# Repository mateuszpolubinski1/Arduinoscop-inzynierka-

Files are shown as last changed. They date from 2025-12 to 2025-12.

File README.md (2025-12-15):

# ArduinoScope – Modular Educational Measurement Device
*A universal, low-cost measurement platform based on Raspberry Pi Pico*

19797808-9ae3-465f-a71c-d99da3b4bd1f

---

## Overview
ArduinoScope is a **modular electronic measurement device** designed as an educational platform for electronics and metrology laboratories.  
The project was developed as an **engineering thesis** and combines **analog front-end design**, **ADC-based signal acquisition**, and **embedded software development**.

The device is built around the **Raspberry Pi Pico (RP2040)** microcontroller and can be reconfigured via software to operate as:
- Oscilloscope
- Spectrum analyzer
- Wobuloscope
- Vector voltmeter
- Frequency counter

---

## System Architecture
The system is based on a **modular architecture**, consisting of a mainboard and multiple plug-in expansion modules.



Key blocks of the system:
- Modular analog input boards
- Mainboard with Raspberry Pi Pico (RP2040)
- Internal ADC for signal acquisition
- TFT display with touchscreen
- USB interface for communication with a PC
- Dedicated power supply module

---

## Analog Front-End Design
Two independent analog input paths were designed to support different measurement scenarios.

### Differential Input Path


- Based on **INA2137 instrumentation amplifier**
- Fixed gain using precision, internally matched resistors
- High common-mode rejection (CMRR)
- Enables voltage measurement between any two points in a circuit
- Dedicated overvoltage protection to protect the ADC

---

### Single-Ended Input Path


- Based on **OPA1644 / TL084 operational amplifiers**
- Electronically adjustable gain
- Separate signal paths for DC and AC components
- Software-controlled signal conditioning similar to a classic oscilloscope
- Input and output protection for safe educational use

---

## Protection & Signal Conditioning
To ensure robustness and safe operation:
- Input protection using **BAV99-AQ diodes** (low leakage, low capacitance)
- ADC protection using **BAS40 Schottky diodes**
- Precision voltage references (**TL431**, **LM385**) for proper ADC range adaptation
- Designed to withstand accidental overvoltage conditions during laboratory exercises

---

## PCB Design
Custom printed circuit boards were designed using **KiCad**, with particular attention to analog signal integrity.











PCB design highlights:
- Modular plug-in boards connected via pin headers
- Noise-aware routing and ground plane usage
- Separation of analog and digital sections
- Easy manufacturing and repair

---

## Software
The firmware was developed using:
- **Arduino**
- **MicroPython**

Main software features:
- Data acquisition from internal ADC
- Signal processing and scaling
- User interface handling (display and touchscreen)
- USB communication for offline data transfer to PC

---

## Measurements & Validation
The device was validated through laboratory measurements.




Validation results:
- Correct operation within the acoustic frequency range
- Stable gain and offset control
- Proper operation of protection circuits
- Reliable signal acquisition using the RP2040 ADC

---

## User Interface
The built-in TFT display provides direct visualization of measured signals.

The user interface allows real-time interaction and configuration without the need for an external computer.

---

## Technologies Used
**Hardware**
- Raspberry Pi Pico (RP2040)
- INA2137, OPA1644, TL084
- AD9850 signal generator
- PCF8575 I/O expander

**Software & Tools**
- Arduino, MicroPython
- KiCad, LTspice
- Oscilloscope and laboratory measurement equipment

---

## Project Status & Future Work
Status:
- Fully functional prototype
- Successfully tested in laboratory conditions

Possible future improvements:
- External higher-resolution ADC
- Improved bandwidth and noise performance
- PC-based visualization and analysis software

---

## Author
**Mateusz Połubiński**  
Electronics Engineering – Warsaw University of Technology

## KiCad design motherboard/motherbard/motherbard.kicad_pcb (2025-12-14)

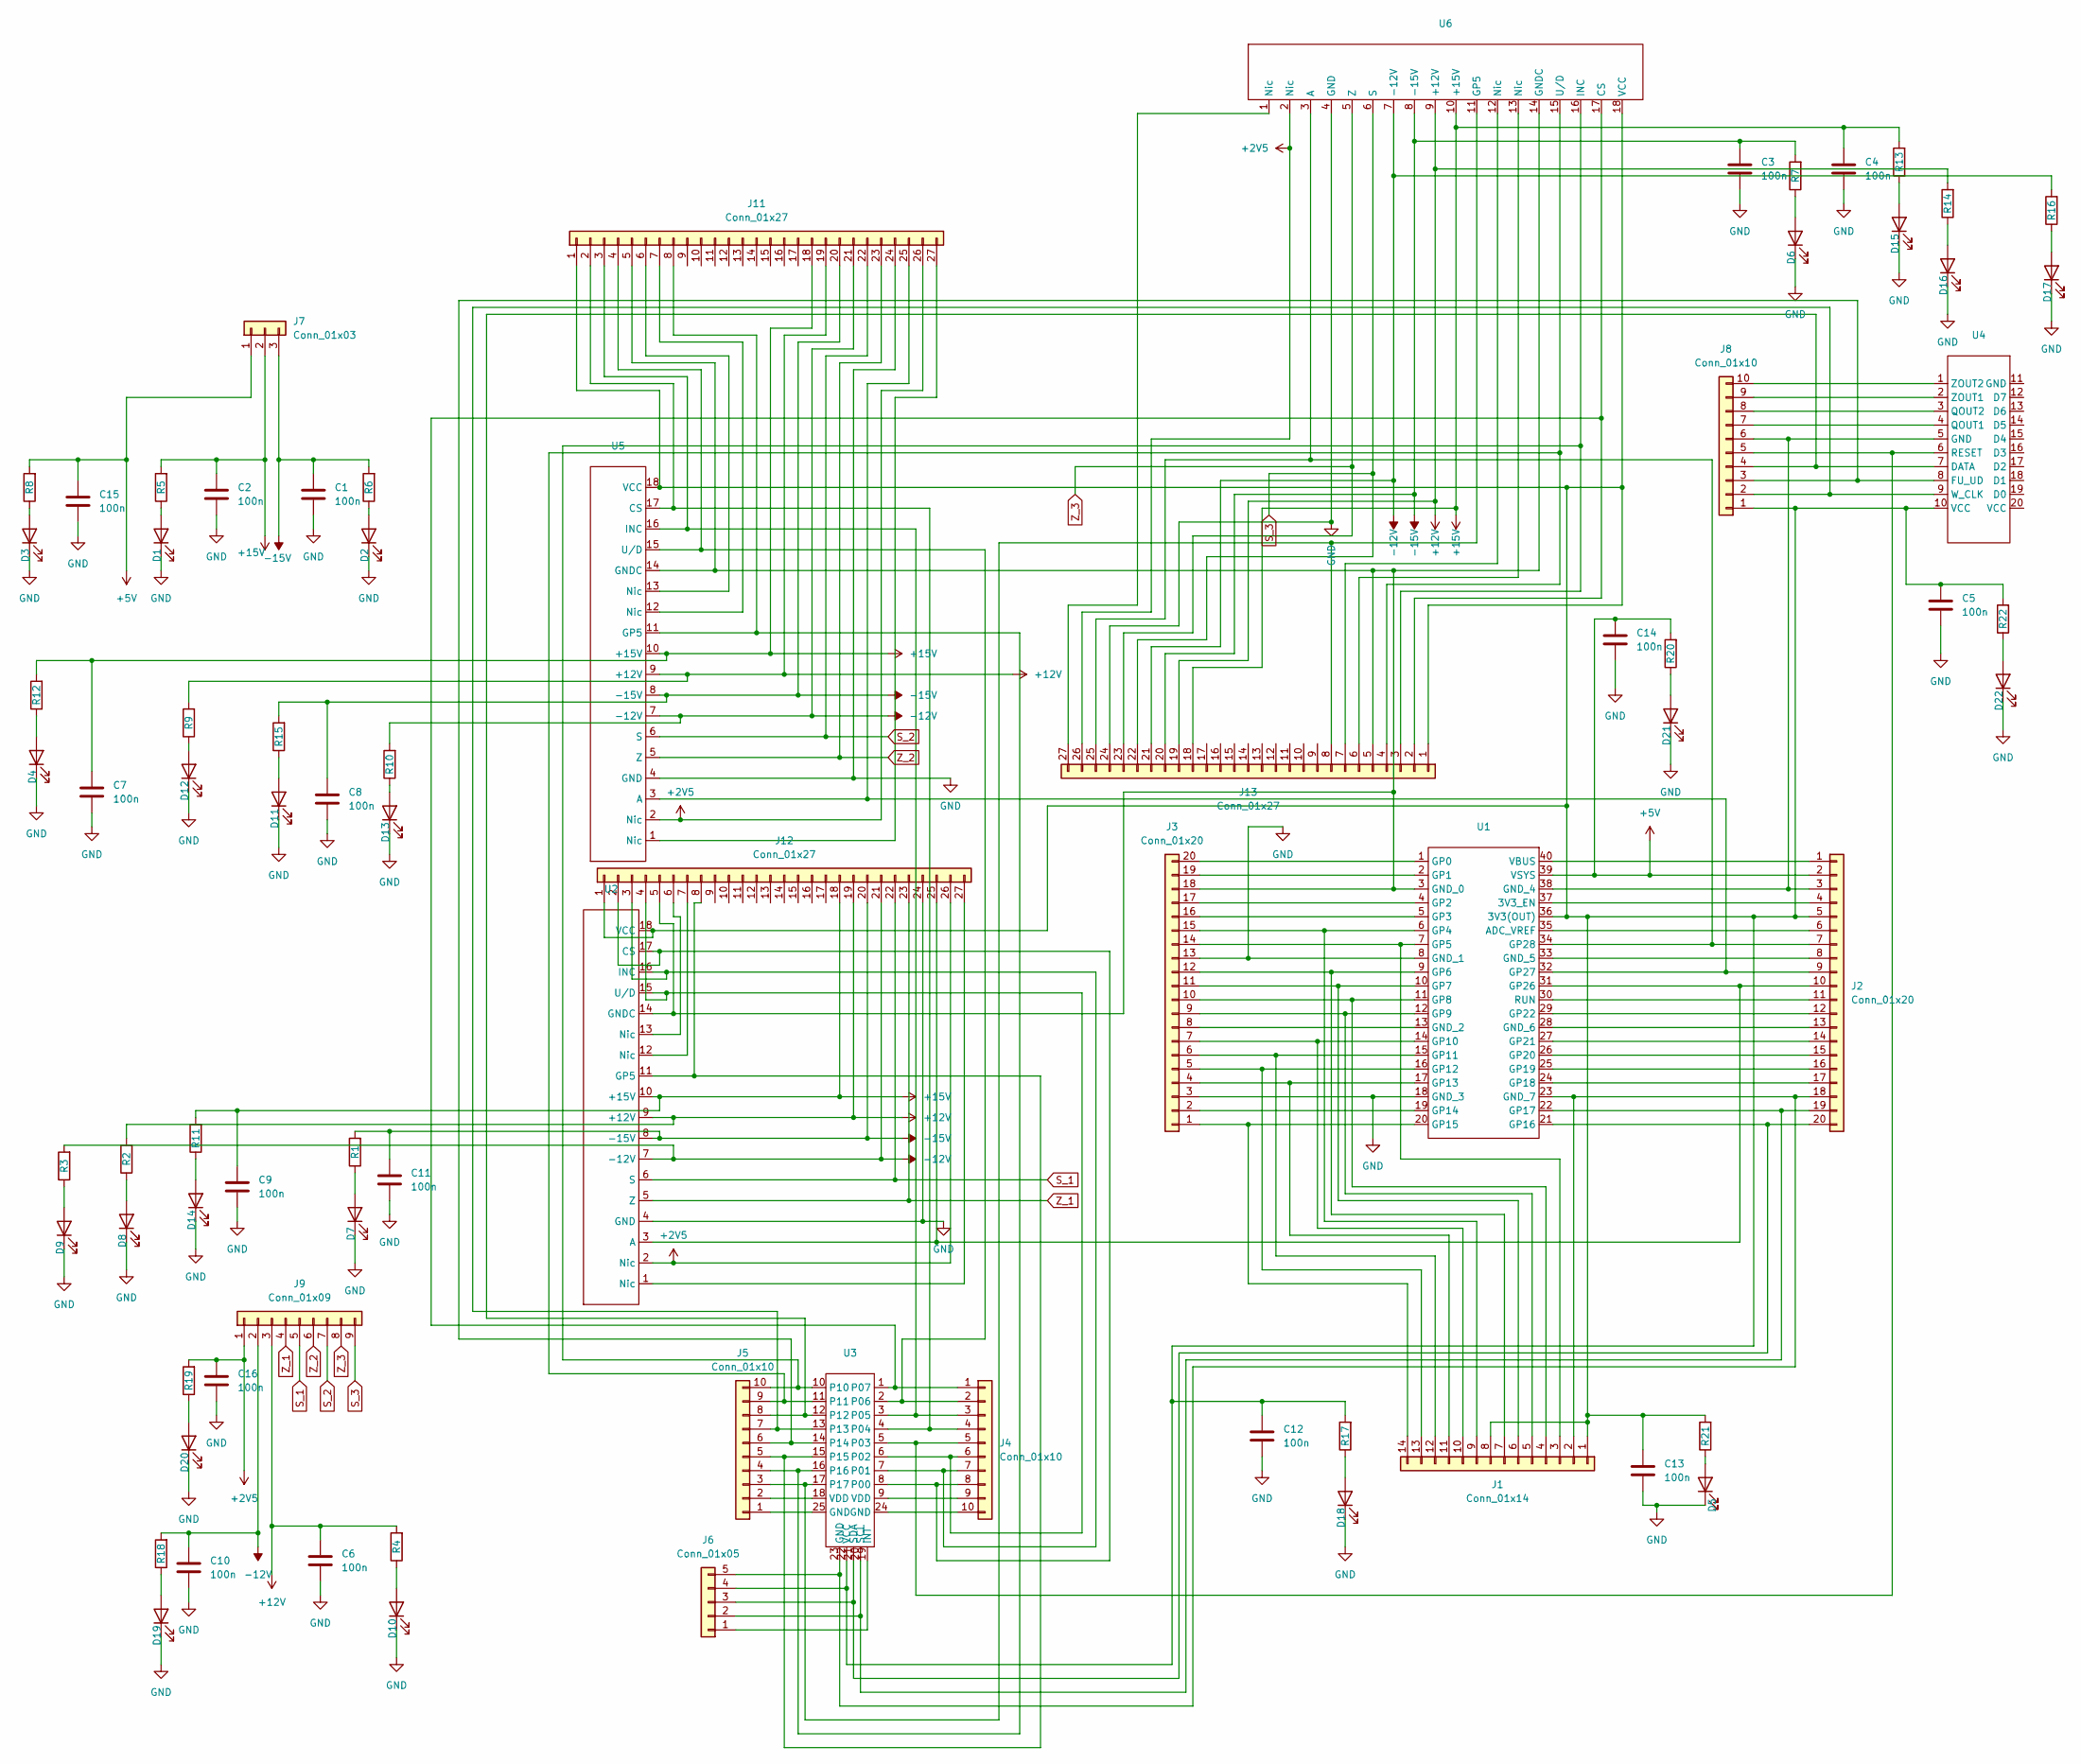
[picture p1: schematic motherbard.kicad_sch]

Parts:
C1, C2, C3, C4, C5, C6, C7, C8, C9, C10, C11, C12, C13, C14, C15, C16: 100n; C_1206_3216Metric_Pad1.33x1.80mm_HandSolder
D1, D2, D3, D4, D5, D6, D7, D8, D9, D10, D11, D12, D13, D14, D15, D16, D17, D18, D19, D20, D21, D22: IR26-21C_L110_TR8; LED_1206_3216Metric
J1: Conn_01x14; PinSocket_1x14_P2.54mm_Vertical
J2, J3: Conn_01x20; PinSocket_1x20_P2.54mm_Vertical
J4, J5, J8: Conn_01x10; PinHeader_1x10_P2.54mm_Vertical
J6: Conn_01x05; PinHeader_1x05_P2.54mm_Vertical
J7: Conn_01x03; PinHeader_1x03_P2.54mm_Vertical
J9: Conn_01x09; PinHeader_1x09_P2.54mm_Vertical
J11, J12, J13: Conn_01x27; PinSocket_1x27_P2.54mm_Vertical
R1, R2, R3, R4, R5, R6, R7, R8, R9, R10, R11, R12, R13, R14, R15, R16, R17, R18, R19, R20, R21, R22: R; R_1206_3216Metric_Pad1.30x1.75mm_HandSolder
U1: raspberry pi pico
U2, U5, U6: płytka
U3: ekspander
U4: generator

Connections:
+2V5: C16.1, J9.1, J11.26, J12.26, J13.26, R19.2, U2.2 (Nic), U5.2 (Nic), U6.2 (Nic)
+5V: C14.1, C15.1, J2.2, J7.1, R8.2, R20.2, U1.39 (VSYS)
+12V: C6.1, J9.3, J11.19, J12.19, J13.19, R2.2, R4.2, R9.2, R14.2, U2.9 (+12V), U5.9 (+12V), U6.9 (+12V)
+15V: C2.1, C4.1, C7.1, C9.1, J7.2, J11.18, J12.18, J13.18, R5.2, R11.2, R12.2, R13.2, U2.10 (+15V), U5.10 (+15V), U6.10 (+15V)
-12V: C10.1, J9.2, J11.21, J12.21, J13.21, R3.2, R10.2, R16.2, R18.2, U2.7 (-12V), U5.7 (-12V), U6.7 (-12V)
-15V: C1.1, C3.1, C8.1, C11.1, J7.3, J11.20, J12.20, J13.20, R1.2, R6.2, R7.2, R15.2, U2.8 (-15V), U5.8 (-15V), U6.8 (-15V)
GND: C1.2, C2.2, C3.2, C4.2, C5.2, C6.2, C7.2, C8.2, C9.2, C10.2, C11.2, C12.2, C13.2, C14.2, C15.2, C16.2, D1.1 (K), D2.1 (K), D3.1 (K), D4.1 (K), D5.1 (K), D6.1 (K), D7.1 (K), D8.1 (K), D9.1 (K), D10.1 (K), D11.1 (K), D12.1 (K), D13.1 (K), D14.1 (K), D15.1 (K), D16.1 (K), D17.1 (K), D18.1 (K), D19.1 (K), D20.1 (K), D21.1 (K), D22.1 (K), J3.3, J3.13, J11.24, J12.24, J13.24, U1.8 (GND_1), U1.18 (GND_3), U2.4 (GND), U5.4 (GND), U6.4 (GND)
unnamed: D1.2 (A), R5.1
unnamed: D2.2 (A), R6.1
unnamed: D3.2 (A), R8.1
unnamed: D4.2 (A), R12.1
unnamed: D5.2 (A), R21.1
unnamed: D6.2 (A), R7.1
unnamed: D7.2 (A), R1.1
unnamed: D8.2 (A), R2.1
unnamed: D9.2 (A), R3.1
unnamed: D10.2 (A), R4.1
unnamed: D11.2 (A), R15.1
unnamed: D12.2 (A), R9.1
unnamed: D13.2 (A), R10.1
unnamed: D14.2 (A), R11.1
unnamed: D15.2 (A), R13.1
unnamed: D16.2 (A), R14.1
unnamed: D17.2 (A), R16.1
unnamed: D18.2 (A), R17.1
unnamed: D19.2 (A), R18.1
unnamed: D20.2 (A), R19.1
unnamed: D21.2 (A), R20.1
unnamed: D22.2 (A), R22.1
unnamed: C5.1, C12.1, C13.1, J1.1, J1.8, J2.5, J6.4, J8.1, J11.1, J12.1, J13.1, R17.2, R21.2, R22.2, U1.36 (3V3(OUT)), U2.18 (VCC), U3.22 (VCC), U4.10 (VCC), U5.18 (VCC), U6.18 (VCC)
unnamed: J1.2, J2.18, J6.5, U1.23 (GND_7), U3.23 (GND)
unnamed: J1.3, J3.14, U1.7 (GP5)
unnamed: J1.4, J3.10, U1.11 (GP8)
unnamed: J1.5, J3.9, U1.12 (GP9)
unnamed: J1.6, J3.11, U1.10 (GP7)
unnamed: J1.7, J3.12, U1.9 (GP6)
unnamed: J1.9, J3.15, U1.6 (GP4)
unnamed: J1.10, J3.7, U1.14 (GP10)
unnamed: J1.11, J3.4, U1.17 (GP13)
unnamed: J1.12, J3.6, U1.15 (GP11)
unnamed: J1.13, J3.5, U1.16 (GP12)
unnamed: J1.14, J3.1, U1.20 (GP15)
unnamed: J2.1, U1.40 (VBUS)
unnamed: J2.3, J8.6, U1.38 (GND_4), U4.5 (GND)
unnamed: J2.4, U1.37 (3V3_EN)
unnamed: J2.6, U1.35 (ADC_VREF)
unnamed: J2.8, U1.33 (GND_5)
unnamed: J2.11, U1.30 (RUN)
unnamed: J2.12, U1.29 (GP22)
unnamed: J2.13, U1.28 (GND_6)
unnamed: J2.14, U1.27 (GP21)
unnamed: J2.15, U1.26 (GP20)
unnamed: J2.16, U1.25 (GP19)
unnamed: J2.17, U1.24 (GP18)
unnamed: J2.19, J6.2, U1.22 (GP17), U3.20 (SCL)
unnamed: J2.20, J6.3, U1.21 (GP16), U3.21 (SDA)
unnamed: J3.2, U1.19 (GP14)
unnamed: J3.8, U1.13 (GND_2)
unnamed: J3.16, U1.5 (GP3)
unnamed: J3.17, U1.4 (GP2)
unnamed: J3.19, U1.2 (GP1)
unnamed: J3.20, U1.1 (GP0)
unnamed: J4.5, J8.5, U3.5 (P03), U4.6 (RESET)
unnamed: J4.9, U3.9 (VDD)
unnamed: J4.10, U3.24 (GND)
unnamed: J5.1, U3.25 (GND)
unnamed: J5.2, U3.18 (VDD)
unnamed: J5.6, J8.3, U3.14, U4.8 (FU_UD)
unnamed: J5.7, J8.2, U3.13, U4.9 (W_CLK)
unnamed: J5.8, J8.4, U3.12, U4.7 (DATA)
unnamed: J6.1, U3.19 (INT)
unnamed: J8.7, U4.4 (QOUT1)
unnamed: J8.8, U4.3 (QOUT2)
unnamed: J8.9, U4.2 (ZOUT1)
unnamed: J8.10, U4.1 (ZOUT2)
unnamed: J4.4, J11.2, U3.4, U5.17 (CS)
unnamed: J4.3, J11.3, U3.3 (P05), U5.16 (INC)
unnamed: J4.2, J11.4, U3.2 (P06), U5.15 (U/D)
unnamed: J3.18, J11.5, J12.5, J13.5, U1.3 (GND_0), U2.14 (GNDC), U5.14 (GNDC), U6.14 (GNDC)
unnamed: J11.6, U5.13 (Nic)
unnamed: J11.7, U5.12 (Nic)
unnamed: J5.4, J11.8, U3.16, U5.11 (GP5)
unnamed: J2.9, J11.25, U1.32 (GP27), U5.3 (A)
unnamed: J11.27, U5.1 (Nic)
unnamed: J4.8, J12.2, U2.17 (CS), U3.8 (P00)
unnamed: J4.7, J12.3, U2.16 (INC), U3.7 (P01)
unnamed: J4.6, J12.4, U2.15 (U/D), U3.6 (P02)
unnamed: J12.6, U2.13 (Nic)
unnamed: J12.7, U2.12 (Nic)
unnamed: J5.5, J12.8, U2.11 (GP5), U3.15
unnamed: J2.10, J12.25, U1.31 (GP26), U2.3 (A)
unnamed: J12.27, U2.1 (Nic)
unnamed: J4.1, J13.2, U3.1 (P07), U6.17 (CS)
unnamed: J5.10, J13.3, U3.10, U6.16 (INC)
unnamed: J5.9, J13.4, U3.11, U6.15 (U/D)
unnamed: J13.6, U6.13 (Nic)
unnamed: J13.7, U6.12 (Nic)
unnamed: J5.3, J13.8, U3.17, U6.11 (GP5)
unnamed: J2.7, J13.25, U1.34 (GP28), U6.3 (A)
unnamed: J13.27, U6.1 (Nic)
S_1: J9.5, J12.22, U2.6 (S)
S_2: J9.7, J11.22, U5.6 (S)
S_3: J9.9, J13.22, U6.6 (S)
Z_1: J9.4, J12.23, U2.5 (Z)
Z_2: J9.6, J11.23, U5.5 (Z)
Z_3: J9.8, J13.23, U6.5 (Z)

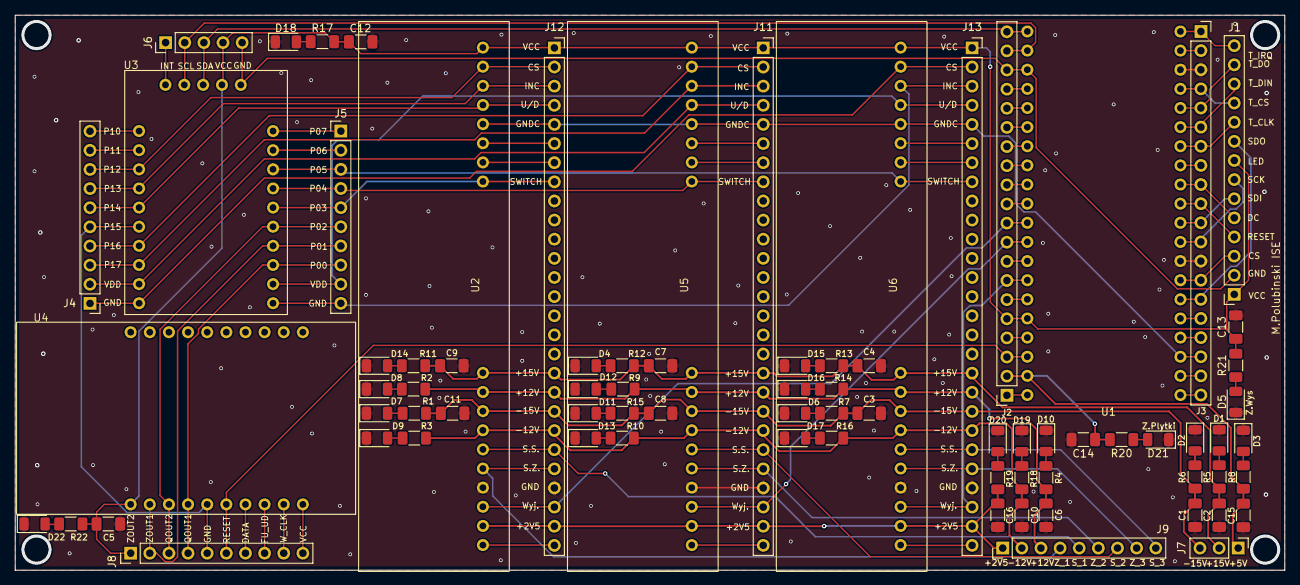
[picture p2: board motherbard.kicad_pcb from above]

Board: 2 copper layers, 168.5 x 73.7 mm, 78 parts (0 on the bottom side), 106 nets.

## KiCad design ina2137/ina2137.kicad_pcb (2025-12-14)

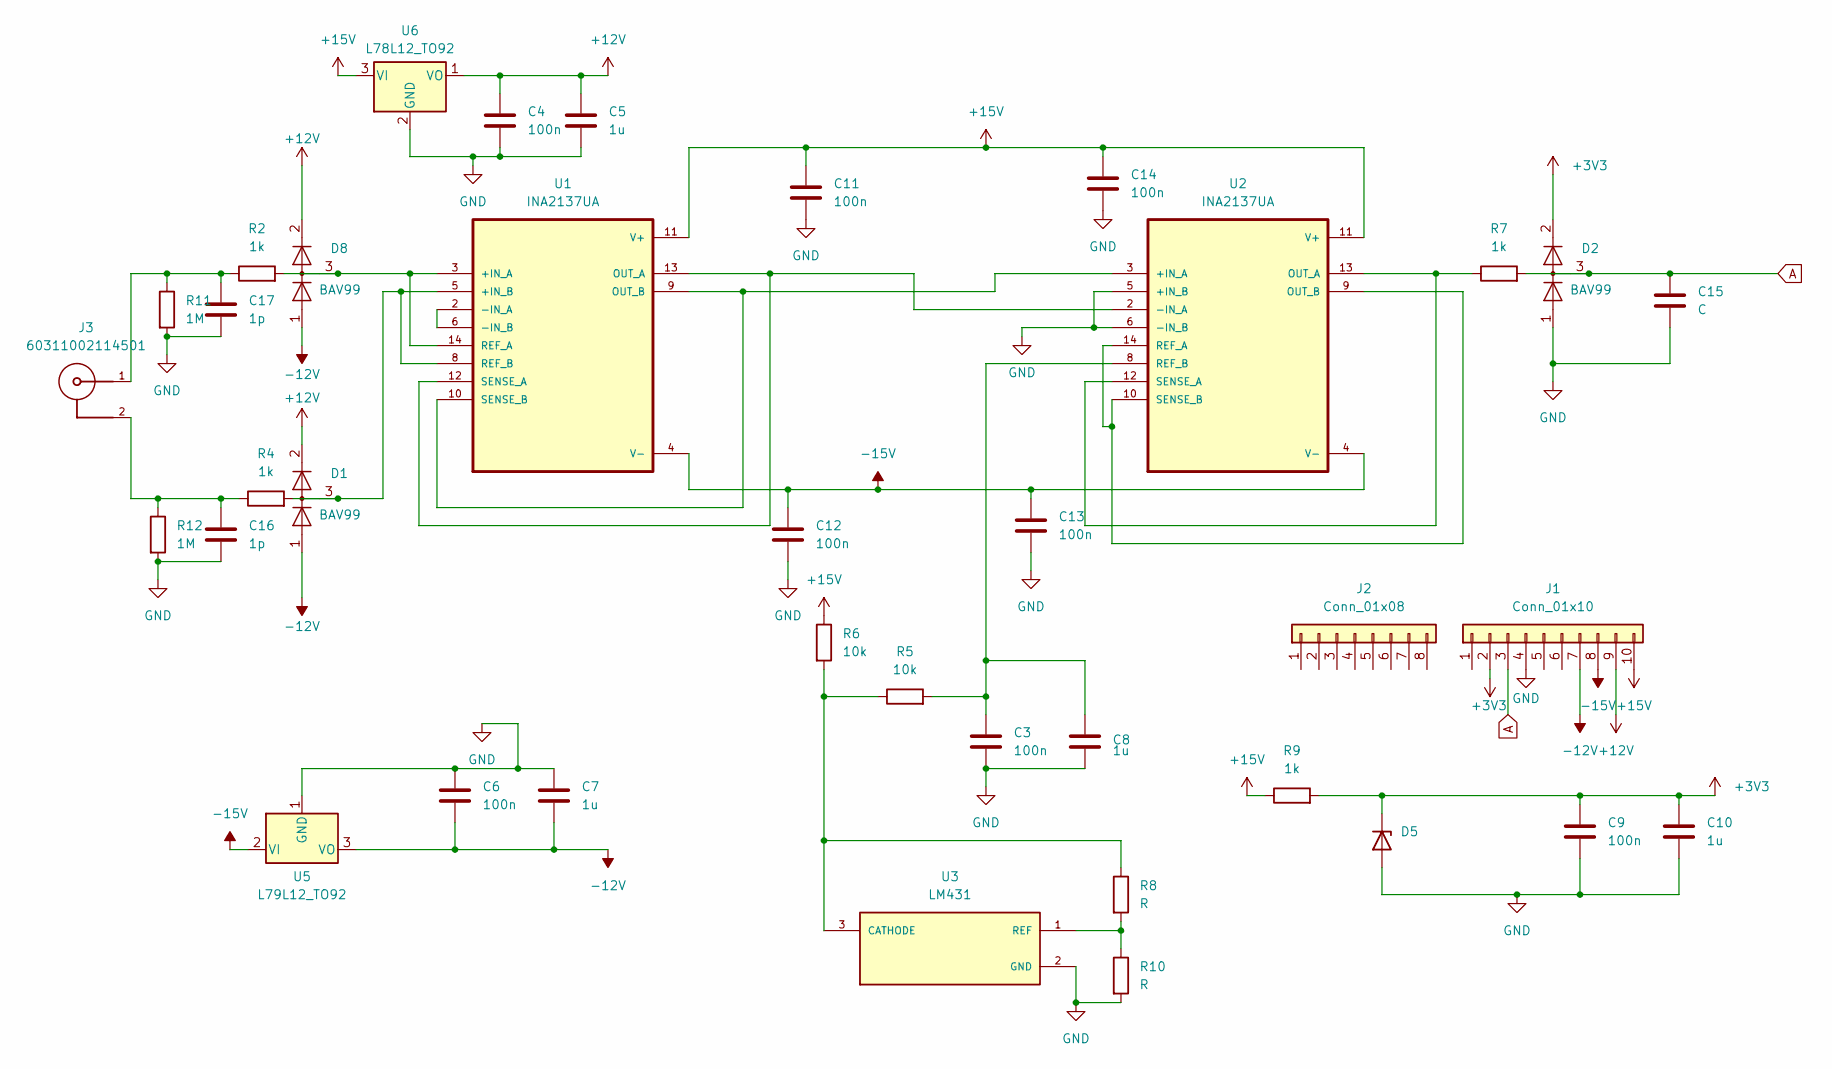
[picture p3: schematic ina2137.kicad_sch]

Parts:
C3, C4, C6, C9, C11, C12, C13, C14: 100n; C_1206_3216Metric_Pad1.33x1.80mm_HandSolder
C5, C7, C8, C10: 1u; CP_Radial_Tantal_D7.0mm_P5.00mm
C15: C; C_1206_3216Metric_Pad1.33x1.80mm_HandSolder
C16, C17: 1p; C_1206_3216Metric_Pad1.33x1.80mm_HandSolder
D1, D2, D8: BAV99; SOT-23
D5: D_A-405_P2.54mm_Vertical_KathodeUp
J1: Conn_01x10; PinHeader_1x10_P2.54mm_Vertical
J2: Conn_01x08; PinHeader_1x08_P2.54mm_Vertical
J3: 60311002114501; SMA_Molex_73251-2200_Horizontal; PART-NUMBER 60311002114501
R2, R4, R7, R9: 1k; R_1206_3216Metric_Pad1.30x1.75mm_HandSolder
R5, R6: 10k; R_1206_3216Metric_Pad1.30x1.75mm_HandSolder
R8, R10: R; R_1206_3216Metric_Pad1.30x1.75mm_HandSolder
R11, R12: 1M; R_1206_3216Metric_Pad1.30x1.75mm_HandSolder
U1, U2: INA2137UA; SOIC127P600X175-14N
U3: LM431; TO-92
U5: L79L12_TO92; TO-92_Inline
U6: L78L12_TO92; TO-92_Inline

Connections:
+3V3: C9.1, C10.1, D2.2 (A), D5.1 (K), J1.2, R9.2
+12V: C4.1, C5.1, D1.2 (A), D8.2 (A), J1.9, U6.1 (VO)
+15V: C11.1, C14.1, J1.10, R6.1, R9.1, U1.11 (V+), U2.11 (V+), U6.3 (VI)
-12V: C6.2, C7.2, D1.1 (K), D8.1 (K), J1.7, U5.3 (VO)
-15V: C12.1, C13.1, J1.8, U1.4 (V-), U2.4 (V-), U5.2 (VI)
A: C15.1, D2.3 (K), J1.3, R7.2
GND: C3.2, C4.2, C5.2, C6.1, C7.1, C8.2, C9.2, C10.2, C11.2, C12.2, C13.2, C14.2, C15.2, C16.2, C17.2, D2.1 (K), D5.2 (A), J1.4, R10.2, R11.2, R12.2, U2.5 (+IN_B), U2.6 (-IN_B), U3.2 (GND), U5.1 (GND), U6.2 (GND)
unnamed: C16.1, J3.2, R4.1, R12.1
unnamed: C17.1, J3.1, R2.1, R11.1
unnamed: D8.3 (K), R2.2, U1.3 (+IN_A), U1.14 (REF_A)
unnamed: D1.3 (K), R4.2, U1.5 (+IN_B), U1.8 (REF_B)
unnamed: U1.2 (-IN_A), U1.6 (-IN_B)
unnamed: U1.12 (SENSE_A), U1.13 (OUT_A), U2.2 (-IN_A)
unnamed: U1.9 (OUT_B), U1.10 (SENSE_B), U2.3 (+IN_A)
unnamed: R7.1, U2.12 (SENSE_A), U2.13 (OUT_A)
unnamed: U2.9 (OUT_B), U2.10 (SENSE_B), U2.14 (REF_A)
unnamed: C3.1, C8.1, R5.2, U2.8 (REF_B)
unnamed: R5.1, R6.2, R8.1, U3.3 (CATHODE)
unnamed: R8.2, R10.1, U3.1 (REF)

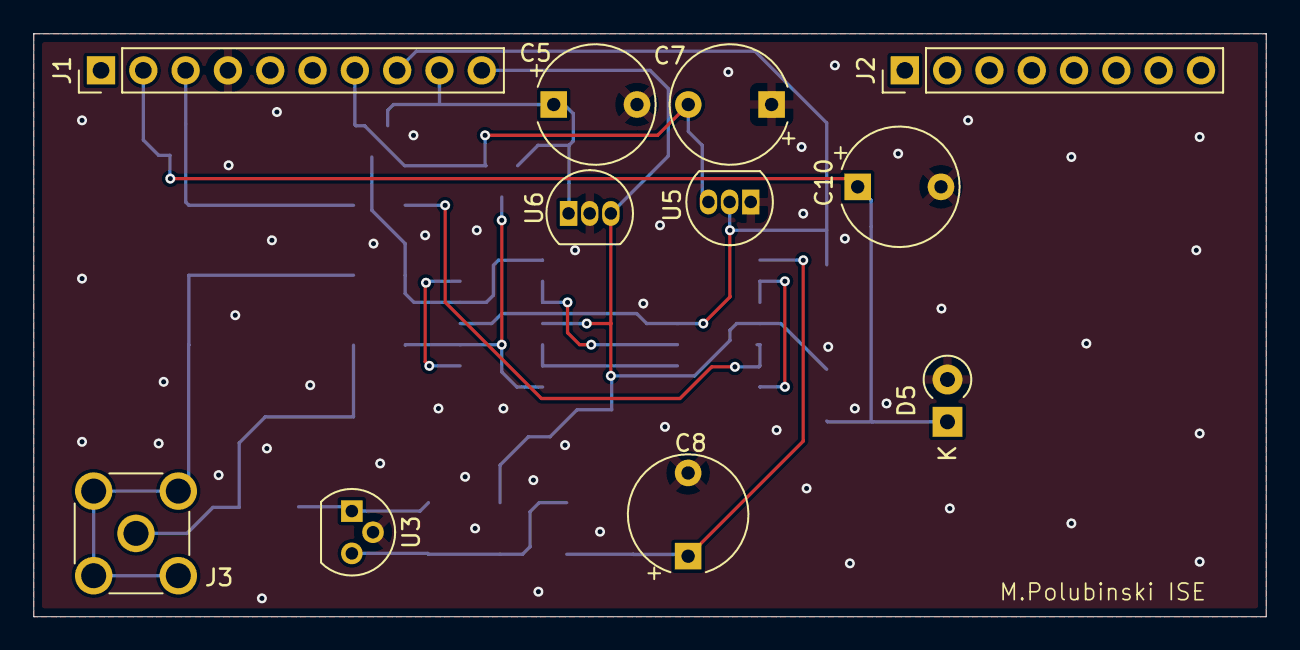
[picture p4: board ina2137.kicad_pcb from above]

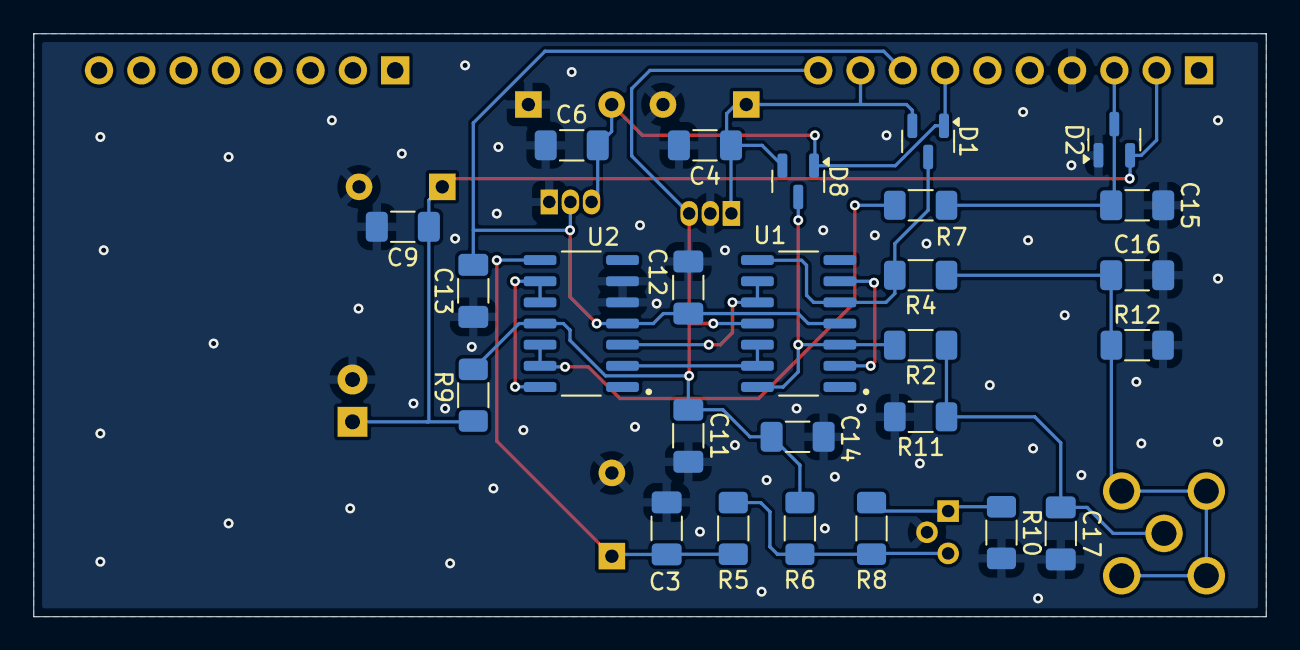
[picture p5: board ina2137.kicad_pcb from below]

Board: 2 copper layers, 74.0 x 35.0 mm, 37 parts (26 on the bottom side), 19 nets.

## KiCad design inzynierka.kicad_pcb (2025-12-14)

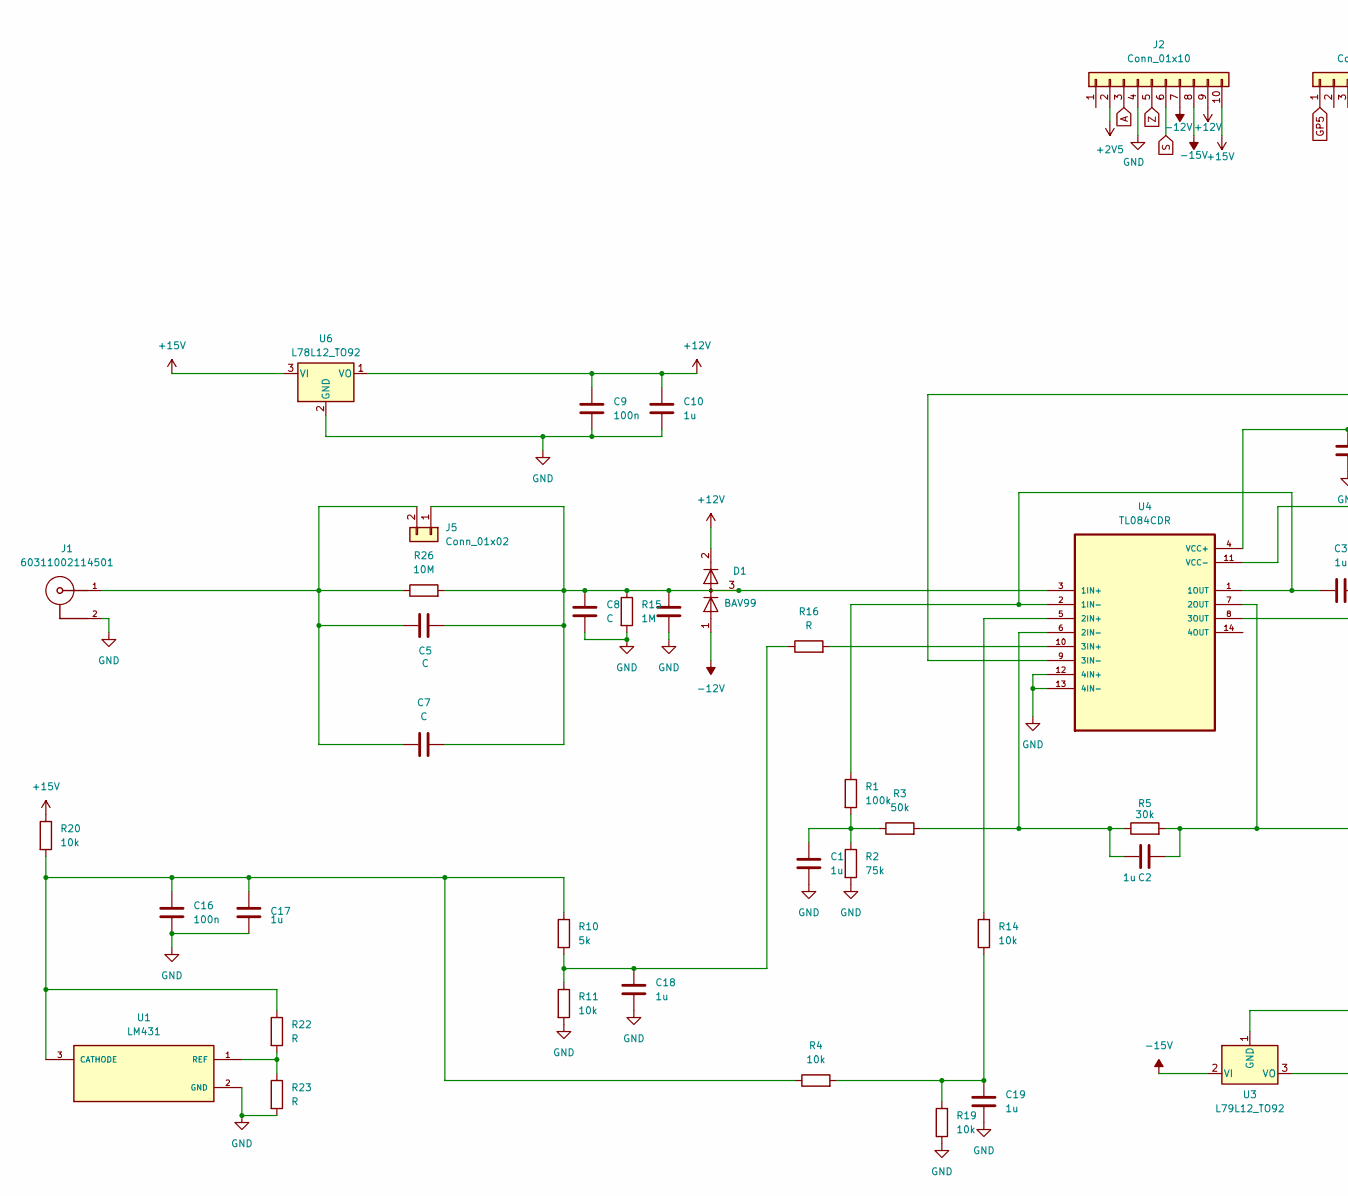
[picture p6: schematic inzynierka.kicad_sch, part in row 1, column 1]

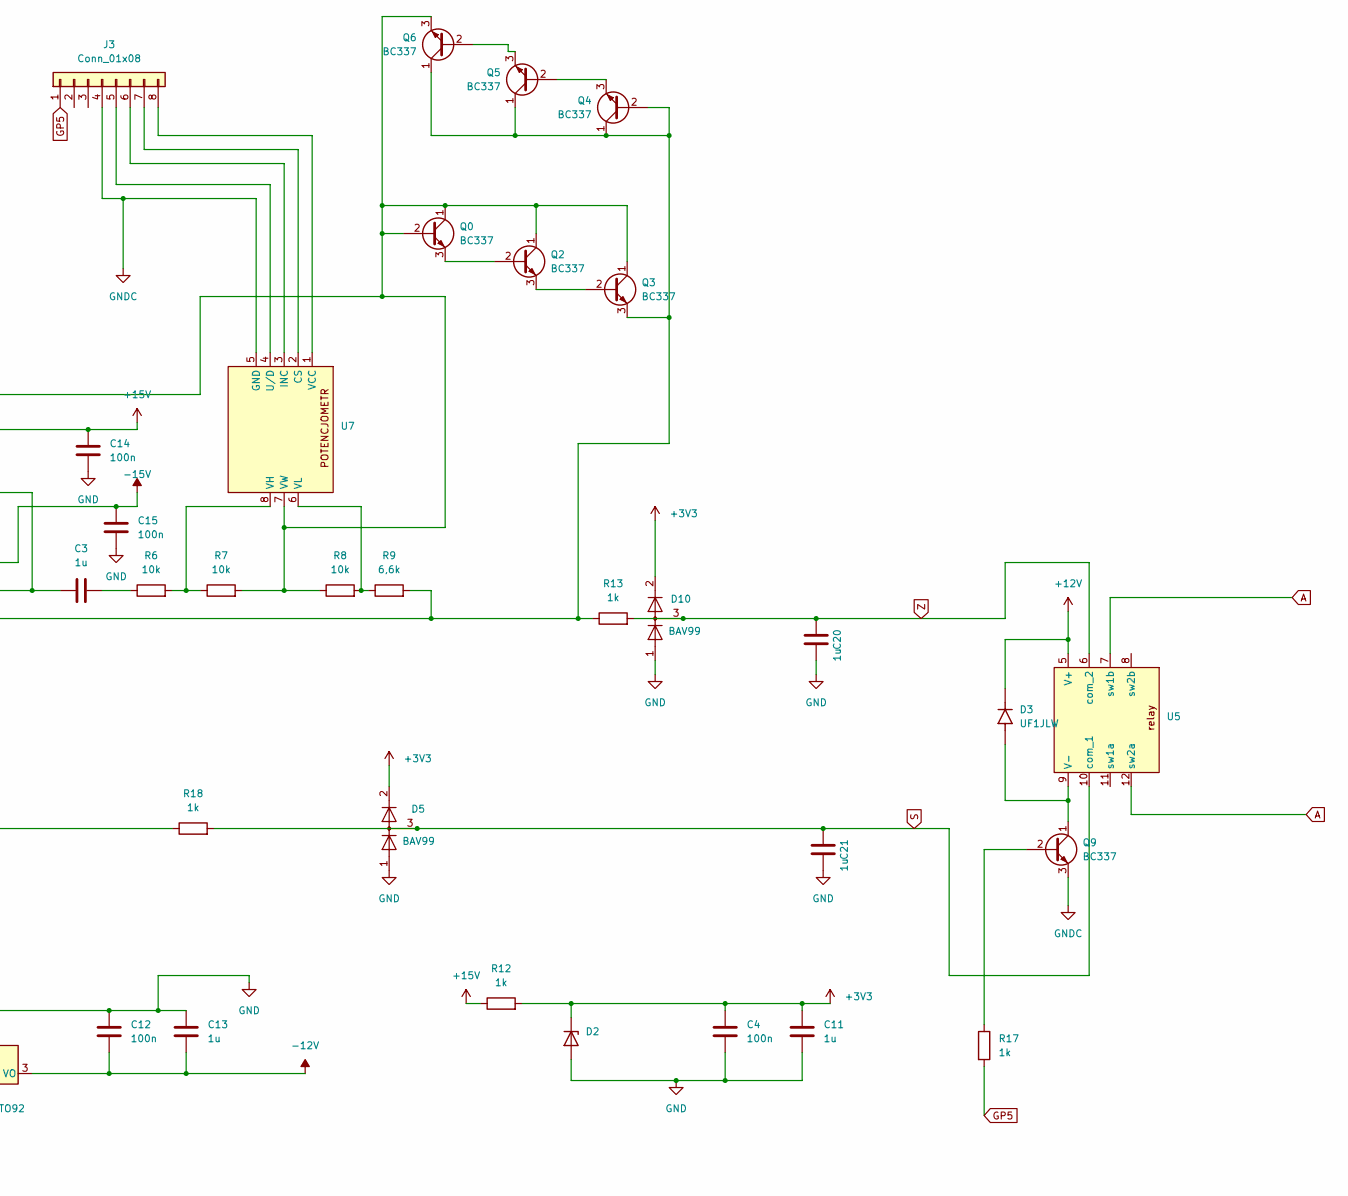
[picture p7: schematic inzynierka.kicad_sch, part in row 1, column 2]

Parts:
C1, C2, C3: 1u; C_1206_3216Metric
C4, C9, C12, C14, C15: 100n; C_1206_3216Metric
C5, C6, C8: C; C_1206_3216Metric
C7: C; CP_Radial_Tantal_D5.5mm_P5.00mm
C10, C11, C13, C17: 1u; CP_Radial_Tantal_D7.0mm_P5.00mm
C16: 100n; C_1206_3216Metric_Pad1.33x1.80mm_HandSolder
C18, C19, C20, C21: 1u; C_1206_3216Metric_Pad1.33x1.80mm_HandSolder
D1, D5, D10: BAV99; SOT-23
D2: D_A-405_P2.54mm_Vertical_KathodeUp
D3: UF1JLW; SODFL3718X102N; PARTREV C2103
J1: 60311002114501; SMA_Molex_73251-2200_Horizontal; PART-NUMBER 60311002114501
J2: Conn_01x10; PinHeader_1x10_P2.54mm_Vertical
J3: Conn_01x08; PinHeader_1x08_P2.54mm_Vertical
J5: Conn_01x02; PinHeader_1x02_P2.54mm_Vertical
Q0, Q2, Q3, Q4, Q5, Q6, Q9: BC337; TO-92_Inline
R1: 100k; R_1206_3216Metric
R2: 75k; R_1206_3216Metric
R3: 50k; R_1206_3216Metric
R4, R6, R7, R8, R11, R14: 10k; R_1206_3216Metric
R5: 30k; R_1206_3216Metric
R9: 6,6k; R_1206_3216Metric
R10: 5k; R_1206_3216Metric
R12, R13, R17, R18: 1k; R_1206_3216Metric
R15: 1M; R_1206_3216Metric
R16, R22, R23: R; R_1206_3216Metric_Pad1.30x1.75mm_HandSolder
R19, R20: 10k; R_1206_3216Metric_Pad1.30x1.75mm_HandSolder
R26: 10M; R_1206_3216Metric
U1: LM431; TO-92
U3: L79L12_TO92; TO-92_Inline
U4: TL084CDR; SOIC127P600X175-14N
U5: relay
U6: L78L12_TO92; TO-92_Inline
U7: X9C1035 Digital Potentiometer

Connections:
+2V5: J2.2
+3V3: C4.1, C11.1, D2.1 (K), D5.2 (A), D10.2 (A), R12.2
+12V: C9.1, C10.1, D1.2 (A), D3.C, J2.9, U5.5 (V+), U6.1 (VO)
+15V: C14.1, J2.10, R12.1, R20.1, U4.4 (VCC+), U6.3 (VI)
-12V: C12.2, C13.2, D1.1 (K), J2.7, U3.3 (VO)
-15V: C15.1, J2.8, U3.2 (VI), U4.11 (VCC-)
A: J2.3, U5.7 (sw1b), U5.12 (sw2a)
GND: C1.2, C4.2, C6.2, C8.2, C9.2, C10.2, C11.2, C12.1, C13.1, C14.2, C15.2, C16.2, C17.2, C18.2, C19.2, C20.1, C21.1, D2.2 (A), D5.1 (K), D10.1 (K), J1.2, J2.4, R2.2, R11.2, R15.2, R19.1, R23.2, U1.2 (GND), U3.1 (GND), U4.12 (4IN+), U4.13 (4IN-), U6.2 (GND)
GNDC: J3.4, Q9.3 (E), U7.5 (GND)
GP5: J3.1, R17.2
unnamed: C1.1, R1.2, R2.1, R3.1
unnamed: C3.2, R6.1
unnamed: C18.1, R10.2, R11.1, R16.1
unnamed: C19.1, R4.2, R14.1, R19.2
unnamed: J3.5, U7.4 (U/D)
unnamed: J3.6, U7.3 (INC)
unnamed: J3.7, U7.2 (CS)
unnamed: J3.8, U7.1 (VCC)
unnamed: C5.2, C6.1, C7.1, C8.1, D1.3 (K), J5.1, R15.1, R26.2, U4.3 (1IN+)
unnamed: C5.1, C7.2, J1.1, J5.2, R26.1
unnamed: Q0.1 (C), Q0.2 (B), Q2.1 (C), Q3.1 (C), Q6.3 (E), R7.2, R8.1, U4.9 (3IN-), U7.7 (VW)
unnamed: Q0.3 (E), Q2.2 (B)
unnamed: Q2.3 (E), Q3.2 (B)
unnamed: Q3.3 (E), Q4.1 (C), Q4.2 (B), Q5.1 (C), Q6.1 (C), R9.2, R13.1, U4.8 (3OUT)
unnamed: Q4.3 (E), Q5.2 (B)
unnamed: Q5.3 (E), Q6.2 (B)
unnamed: Q9.2 (B), R17.1
unnamed: D3.A, Q9.1 (C), U5.9 (V-)
unnamed: C16.1, C17.1, R4.1, R10.1, R20.2, R22.1, U1.3 (CATHODE)
unnamed: R22.2, R23.1, U1.1 (REF)
unnamed: C3.1, R1.1, U4.1 (1OUT), U4.2 (1IN-)
unnamed: R14.2, U4.5 (2IN+)
unnamed: C2.1, R3.2, R5.1, U4.6 (2IN-)
unnamed: C2.2, R5.2, R18.1, U4.7 (2OUT)
unnamed: R16.2, U4.10 (3IN+)
unnamed: R6.2, R7.1, U7.8 (VH)
unnamed: R8.2, R9.1, U7.6 (VL)
S: C21.2, D5.3 (K), J2.6, R18.2, U5.10 (com_1)
Z: C20.2, D10.3 (K), J2.5, R13.2, U5.6 (com_2)

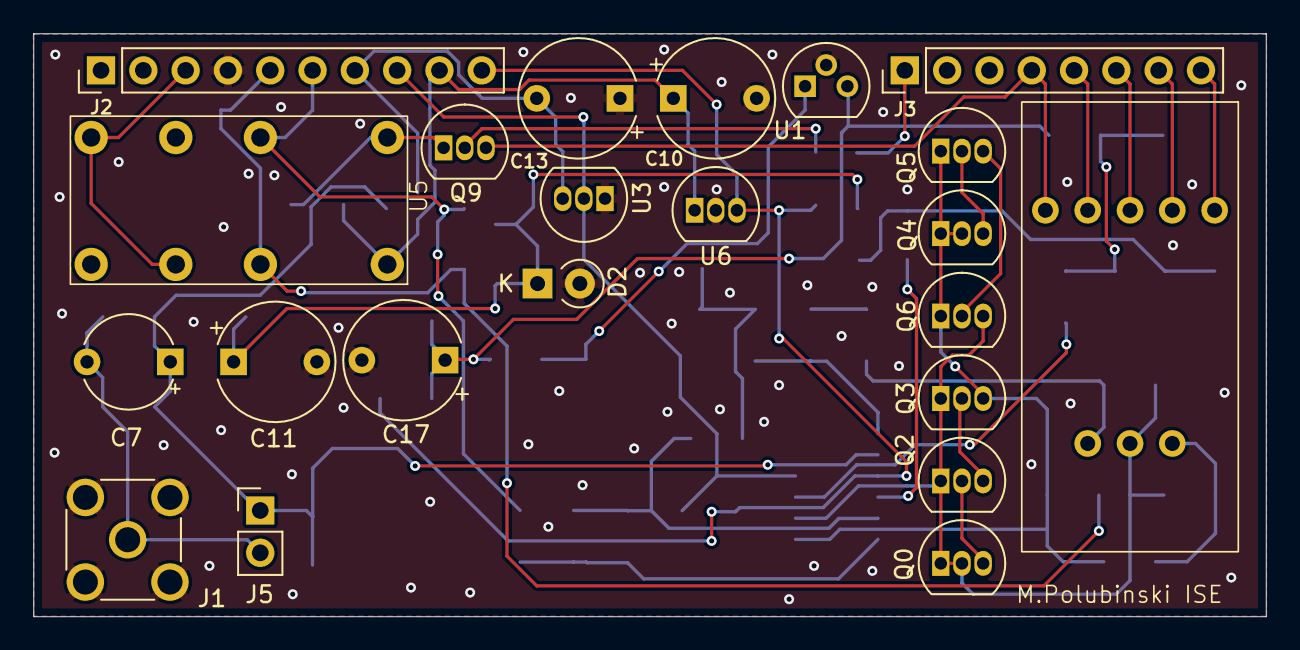
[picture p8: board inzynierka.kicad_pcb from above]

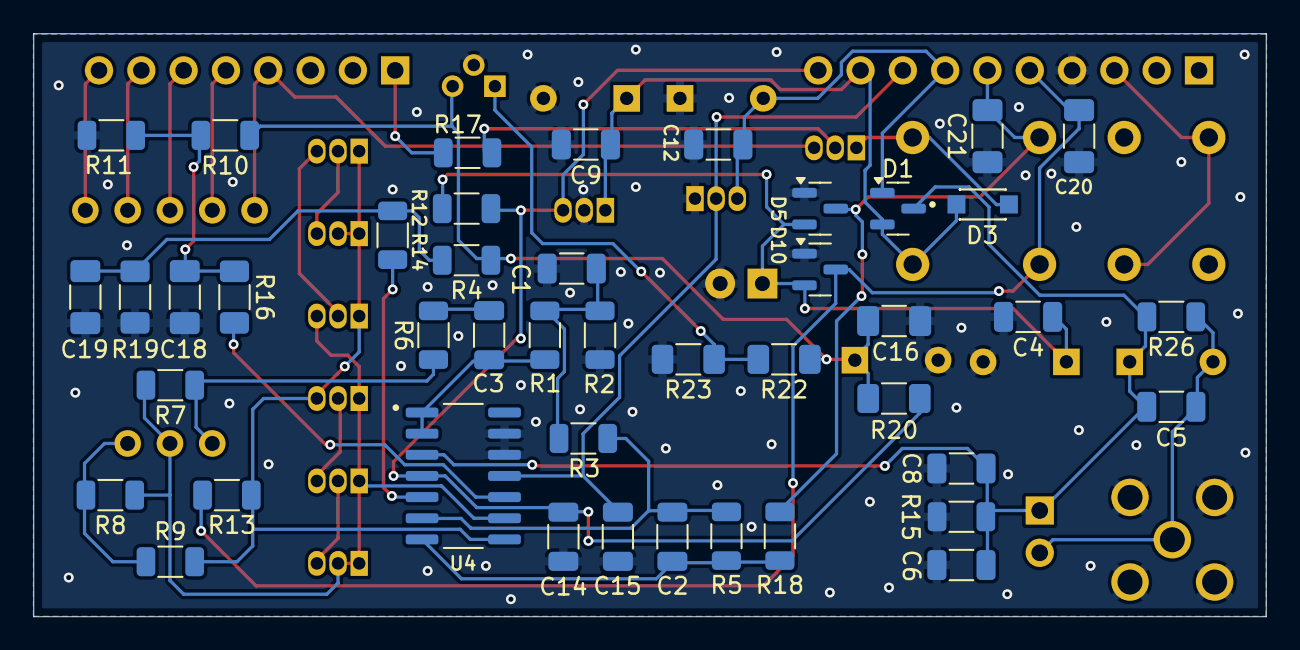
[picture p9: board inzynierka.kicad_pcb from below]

Board: 2 copper layers, 74.0 x 35.0 mm, 66 parts (44 on the bottom side), 38 nets.
